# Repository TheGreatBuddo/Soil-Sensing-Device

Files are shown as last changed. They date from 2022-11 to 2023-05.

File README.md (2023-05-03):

# Soil-Sensing-Device Readme

Welcome to Twin Cities Engineering's project on soil health monitoring 
through gas-based measurement! Soil health plays a critical role in
agriculture and environmental sustainability. Measuring gases in soil pore 
spaces is an effective way to monitor soil health, providing valuable 
information about the soil's nutrient content and microorganism activity. 
However, commercially available gas-based soil health measurement devices 
are prohibitively expensive, limiting their accessibility to farmers and 
soil scientists. To address this issue, our engineering project team is 
developing a low-cost DIY soil gas sensing unit capable of 
measuring oxygen, carbon dioxide, and methane concentrations at 
four soil depths every hour. Our goal is to create a prototype 
that is affordable, portable, and easy to use, 
empowering more people to measure and monitor soil health.

Our project is centered around a device that attaches to four soil 
probes of varying lengths (0.25, 0.5, 0.75, and 1 meter) to extract 
soil gases. These probes are placed in a 1-meter squared area of soil, 
assuming that the soil gas concentrations will remain constant. 
The device has four ports for tubes that connect from the probes 
to the device, and each port connects to a solenoid valve inside the 
device. These valves can be opened and closed by a Mayfly microcontroller, 
allowing the device to be exposed to one probe at a time. 
A sensor chamber houses four sensors, including 
an Alphasense IRC-AT carbon dioxide sensor, Alphasense O2-A3 oxygen sensor,
and TGS2611-E00 methane sensor, along with a bme280 temperature, pressure,
and humidity sensor. The final component in the sensor chamber is a 
heating element, which is designed to prevent condensation from forming 
and potentially damaging the sensors. If the bme280 detects a dew point, 
the heating element is activated.

All work accomplished can be found in the Final Design Document and more
discussion about the project. A poster has been developed for this project
and is also uploaded in the repository. Lastly STL files for the sensor chamber
and the program to control the device are included.

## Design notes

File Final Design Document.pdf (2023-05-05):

Final Design Document

Twin Cities Engineering

Project Team Students: David Schaeppi, Samuel Day, Kevin Lee, Brendan Dykes, and Jeodaun Lee

Spring 2023 Semester

May 5th, 2023

## Contents

## Introduction

A revolution of farmers interested in smart regenerative agricultural practices has blossomed over recent years. Many farmers of these communities are actively seeking stem tools to help monitor soil health and provide feedback to farmers on the quality of their practice. One method to measure soil health is to measure the gases within the soil. Measuring certain gases in soil provides information about the nutrients and microorganism activity within the soil. Commercially available soil pore space gas instruments are costly, with the cheapest systems costing around $100,000. The high costs leave a demand for a low budget system capable of extracting, measuring, and reporting soil gas concentrations.

To address this issue, a team of engineering students from Twin Cities Engineering at the University of Minnesota, Mankato, is planning to develop a low-cost DIY soil sensing unit. The unit will be designed to extract soil gases from four different depths, providing farmers with valuable information about their soil health. The team plans to make all the information about the project available on GitHub, an open-source platform for software development, so that other farmers and researchers can benefit from their work. By developing a low-cost soil sensing unit, the team hopes to make it easier for farmers to adopt smart regenerative agricultural practices and improve the sustainability of their farming operations.

The DIY soil sensing unit will consist of a gas sampling chamber, a vacuum pump, and an electronic sensor for detecting the gases. The team plans to use off-the-shelf components wherever possible to keep the costs low. They are also exploring the use of 3D printing technology to produce some of the components. The device will be powered by a rechargeable battery, which will be recharged with solar power, making it easy to use in the field.

In addition to providing farmers with information about their soil health, the team hopes that their project will also help to raise awareness about the importance of soil health and the role of regenerative agricultural practices in promoting sustainable agriculture. By sharing their work on GitHub, they aim to inspire others to develop similar low-cost solutions and contribute to the growing community of farmers interested in regenerative agriculture.

Current State of the Art

There are a few longstanding methods of acquiring this data from under the soil, one being gas chromatography. This is done in a large lab space where samples of the trapped gas or soil sample are brough to the lab and examined in these large machines. The chromatography machine is, bulky, high-energy cost and high dollar cost. The next champion in this segment is the FTIR.

Fourier Transform Infrared (FTIR) spectroscopy is a powerful analytical technique that can be used to analyze the composition of specific gases in soil vapor. The technique involves measuring the absorption of infrared radiation by a sample and then using this information to determine the types and amounts of molecules present in the sample.

FTIR spectroscopy works by passing infrared radiation through a sample, such as soil vapor, and measuring the amount of radiation absorbed by the sample at specific wavelengths. Different molecules absorb radiation at different wavelengths, and the resulting spectra can be used to identify the types and amounts of molecules present in the sample.

When applied to soil vapor, FTIR spectroscopy can be used to identify and quantify the concentrations of various gases, such as carbon dioxide, methane, and nitrous oxide. These gases are important indicators of soil health and can provide valuable information about soil microbial activity, nutrient cycling, and greenhouse gas emissions. So the FTIR is a force. However, this is an industry machine that costs in 100k range and requires a great deal of power. More power than we could get out of a 2ftx2ft solar array

What is the Device:

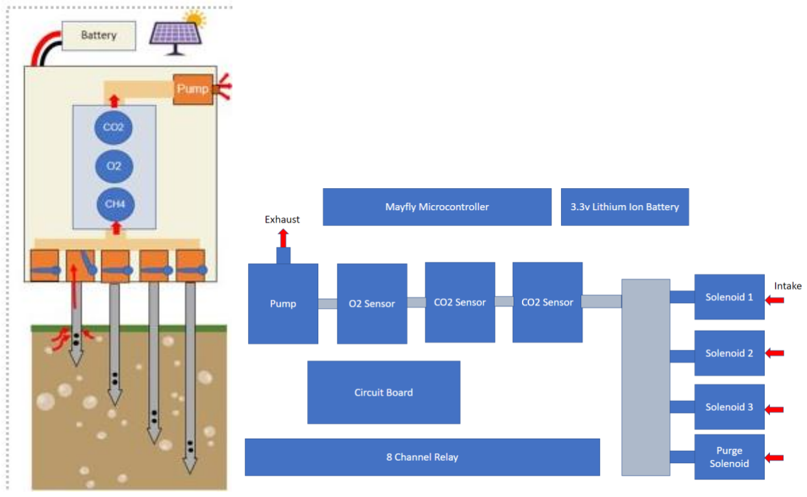
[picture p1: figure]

The images above are diagrams of the system we received from the previous team.

The Device a machine that will stay outside all growing season, it will use a solar panel to charge its batteries. It will be able to accurate a pump to draw gas from under the soil from 4 different depths, run that gas over our sensors and record the concertation of Co2, O2, and CH4. After the reading has been taken, the gas is removed from the chamber via that same pump and ejected through a port in the top of the machine. The data is then saved to an SD card as well as relevant information about Time, Date. Temperature, and Humidity.

## Project Tutorial

### Project Timeline

- Spring 2022
- Developed groundwork for entire soil sensing unit design
- Setup a pump, 8 channel relay and sensor hookup
- Fall 2022

- Created Sensor caps to connect sensors together
- Extracted readouts from sensors
- Programmed framework for device operation
- Data storage on SD card
- Eliminated solenoid noise triggering relay issue using snubbers
- Attempted to implement a methane sensor but fried it
- Spring 2023
- Created a sensor chamber included with temperature control
- Created a prototype bulk water removal system
- Fully implemented entire design into a box for total mobility
- Implemented a low-cost methane sensor
- Properly extract gas from probes
- Completed a GitHub Repository

### Device Design

Design Intent
The soil gas sensor device is designed to provide accurate and precise measurements of gas concentrations in soil. It consists of four soil probes of varying lengths (0.25, 0.5, 0.75, and 1 meter) that can be easily attached to the device. Each probe is equipped with holes to extract gas from the soil when a connected pump is activated.

To ensure accurate readings, the four probes are placed in a 1-meter squared area of soil, under the assumption that soil gas concentrations will not vary significantly within this area. The device itself has four ports to connect tubes from the probes to the device. Each port is connected to a solenoid valve inside the device, which can open and close based on the response from a Mayfly microcontroller.

To ensure precise measurements, the device allows for the exposure of one probe at a time while keeping all other valves closed. This process allows the device to accurately measure the gas concentration at each depth, providing valuable insights into the microbial activity and nutrient levels of the soil. By allowing for the measurement of gas concentrations at varying depths, farmers can make informed decisions about the timing and amount of fertilizer application, thus optimizing crop yields while reducing the use of potentially harmful fertilizers.

Behind the solenoids lies the sensor chamber. The sensor chamber houses an Alphasense IRC-AT carbon dioxide sensor, Alphasense O2-A3 oxygen sensor, a TGS2611-E00 methane sensor, a bme280 temperature, pressure, humidity sensor, and a heating element. The heating element is implemented due to our project team’s worry of condensation forming within the sensor chamber and damaging the sensors. The heating element is connected to an H-Bridge and begins heating if dew point is measured from the bme280.

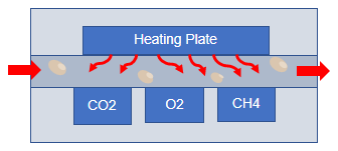
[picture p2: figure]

Figure 1

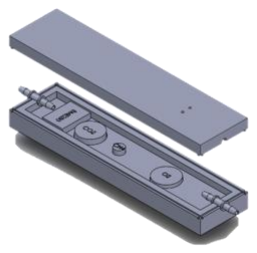
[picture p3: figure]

Figure 2

The Alphasense sensors were chosen due to professor suggestion in the reliability of the brand. Each Alphasense sensor is powered with 12V. To measure the sensors a load resistor of 230 ohms is used for both sensors. The voltage drop across the resistor is measured using an Analog Digital Converter (ADC) to read oxygen and carbon dioxide. The Alphasense IRC-AT has two signal wires. Sig+ connects to one end of the resistor while Sig- connects to the other end. The Alphasense O2-A3 however connects in series. 12 volts powers the O2-A3. The output current is an ADC measurable current of 4-20 mA. The load resistor is placed in series with the O2-A3 sensor for the ADC to measure the voltage drop.

The TGS2611-E00 was chosen due to its low cost and abundant literature claiming the sensor to be a capable low-cost sensor for methane detection. Our team lacks the ability to perform proper laboratory calibrations. Our team assumed we could use equations derived from literature [1] [2], to tune an algorithm to compute relatively accurate ppm readings from measured voltage drop across a load resistor. Our assumptions were wrong.

To compute the TGS2611-E00, ohms law is used to measure the resistance inside the methane sensor. The equation displayed in Equation 1Error! Reference source not found. is used to compute sensor resistance Rs
. For context the sensors circuitry is displayed in Figure 3. The Mayfly ADC measures voltage drop (Vout) across the load resistor Rl

Rs = RL (

Vc

Vout

− 1)
Equation 1

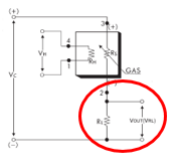
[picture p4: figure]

Figure 3: TGS2611-E00 Sensor Circuit

To convert the ADC’s measured voltage to methane parts per million our team attempted to use equations from Van den Bossche et al [1]. In their paper, Equation (11) converts sensor resistance to methane ppm using a value R0 and measured Rs displayed in Equation 1. R0 is the sensor’s resistance value at a reference point concentration of methane ppm. We recorded R0 in an ambient setting to be equal to 23,250 Ω. Our team recognized we had no way to control environmental factors such as temperature and relative humidity, but we could reference them using measurements from the BME280. When using the equation, we found the trend to compute confusing results. The equation also did not compute an expected trend.

The BME280 was chosen due to its ease of installation. The device has two total BME280s installed with addresses (0x76) and (0x77). (0x76) measures ambient temperature, pressure, and relative humidity within the container of the device. (0x77) measures temperature, pressure, and relative humidity within the sensor chamber. Both the BME280s are used to compare the difference between the ambient environment and inside the sensor chamber. If the temperature is excessively cold out, condensation could occur. Thus, the mayfly continually monitors the temperature and relative humidity inside the sensor chamber to acknowledge when to turn on the heating element.

Device’s Program Flowchart
Shown in Figure 4, the Mayfly microcontroller first reads if any of the bme280 sensors or the external ADC is properly connected. If any of the components are not connected, then the device will not operate. If all components are connected the code will reach Arduino’s loop function. Inside the loop function is a for loop intent on opening one solenoid valve out of four, pumping gas from the solenoid through the device, measuring data, heating the sensor chamber if necessary, and storing the data on a SD card located on the microcontroller itself.

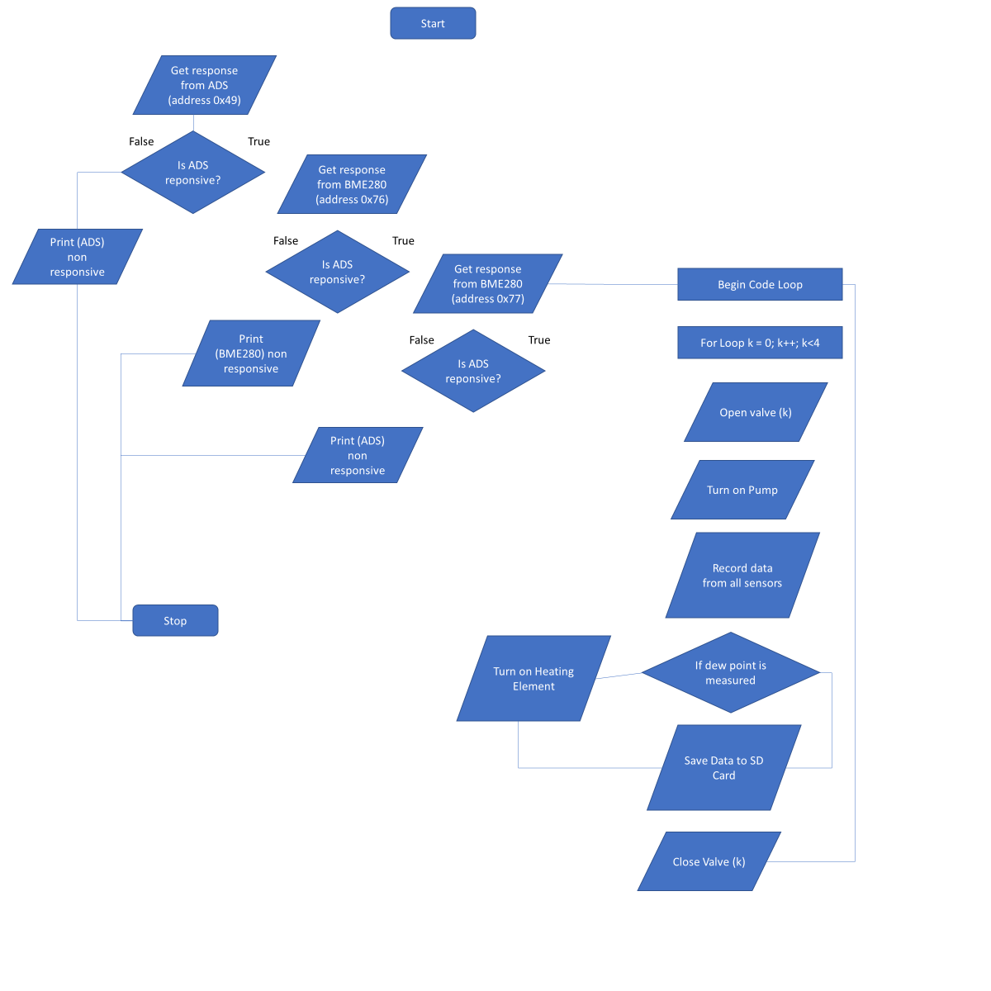
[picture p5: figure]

Figure 4: Program Flowchart

Device Electrical Schematic
The electrical schematic displayed in Figure 5 shows all electrical components wired in the device. At the center of it all, a Mayfly v1.1 microcontroller controls all the operations of the device. Both the Alphasense O2-A3 and the Alphasense IRC-AT voltage readouts are measured using an onboard ADC. An external ADC component, the ADS1115 measures the voltage level of the battery, and measured voltage drop across the load resistor of the TGS2611-E00 methane sensor. The solenoids are controlled with an 8 Channel Relay. Each solenoid is connected to the normally open position. Connected in parallel with each solenoid is a resistor and capacitor in series. These are snubbers intended to dampen AC noise generated when the solenoids are opened or closed. Our project team had a significant problem controlling the relays until the snubbers were installed. To control the pump and heating element, an L298N H-Bridge was used. The H-Bridge can limit voltage supply to the components used Pulse Width Modulation (PWM) from the Mayfly microcontroller.

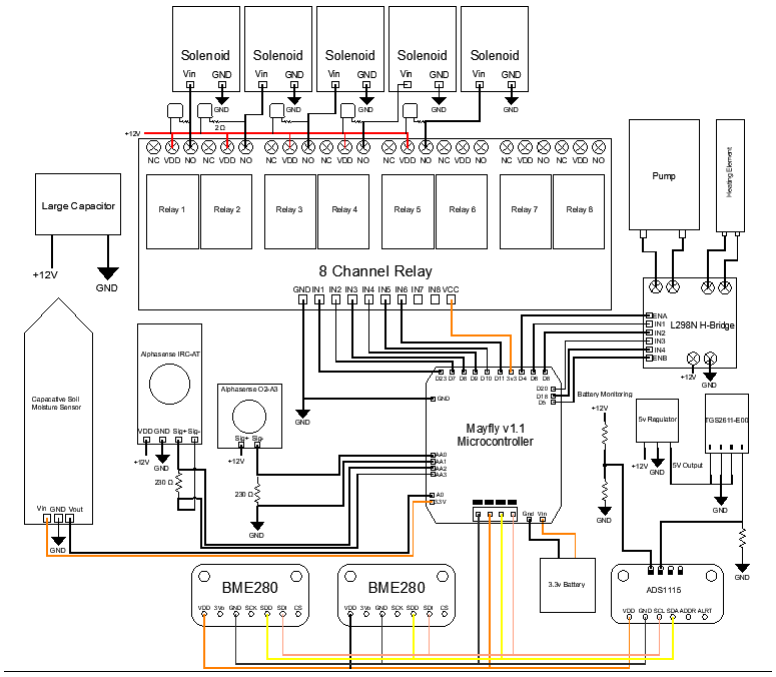
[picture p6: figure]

Figure 5: Electrical Schematic

The Mayfly Microcontroller was chosen due to its capabilities and the microcontrollers focus on being used to monitor environmental conditions in a DIY environment. The EnviroDIY community is behind this device. The Mayfly Microcontroller is based on Arduino and uses the Arduino IDE software for programming. The microcontroller is pivotal for our device because of its range of capabilities. The device uses I2C communication, Analog Digital Converters (ADC), pulse width modulation, and one of the most important points is the number of available pins. In total our device requires 23 individual pins to operate the device leaving the mayfly as a great option.

The solenoids are powered using 12V and controlled from the 8 Channel Relay. Placing the snubbers in parallel with the solenoids is important due to noise generated from the opening and closing of a relay. The noise generated would retrigger the relay even though there was no input. The relay would begin to spasm uncontrollably until the power was turned off. The snubbers absorb AC signal noise and prevent a commonly known issue of the relays going haywire. The solenoids themselves consume a lot of power, about 600 mA per solenoid. The solenoids have been used in all three semesters of this project because the solenoids met the need for testing and designing. All project teams were focused on function and not worried about power consumption.

The L298N H-Bridge is used to control the current supplied to both the pump and heating element using PWM from the Mayfly microcontroller. Both the pump and heating supply are wired to the same H-Bridge but are separately controlled to meet the necessary power consumption. In software the pump is operated at maximum speed to fill the sensor chamber as quickly as possible. For the heating element, about 2 volts was enough to heat the sensor chamber adequately but can be adjusted in the code to either increase or decrease heat output.

The ADS1115 is an Analog Digital Converter (ADC) used to measure the voltage at different points in a circuit. The Mayfly has four onboard ADC pins. Our team is using all four pins to measure the voltage drop across the load resistors of the carbon dioxide and oxygen sensor. Other components we need to measure are the TGS2611 – E00 methane sensor, and the battery voltage. Since our device is planned to eventually be powered by a solar panel, a battery monitoring system has been implemented. The ADS1115 measures from 0 – 5V, but we have it measuring up to 3.3V max due to a warning in the component’s documents. A 100,000-ohm resistor is placed in series with a 10,000-ohm resistor. Using the voltage divider equation and measuring the voltage drop across the 10,000-ohm resistor, the ADS1115 can safely measure voltage and the Mayfly can compute the total voltage supplied by the battery. Lastly the ADS1115 also measures the voltage drop of the TGS2611 - E00’s load resistor and an algorithm are used to convert and compute methane ppm.

The Capacitive soil moisture sensor is used to detect water inside the bulk water removal trap. The Mayfly measures voltage from an analog pin. Currently the program has not implemented any response to water level besides taking measurements. We suggest using measurements from the soil moisture sensor to operate designed water trap.

Water Trap
We chose to use the method of 3D printing to create a water removal unit for the soil project. Full well understanding two things that this method will be able to get a basic design or best shape but the difficult learning curve of the solid works software as this semester is the first time we have engaged with that software.

We started this off by disassembling a commercial water filter, the intent was to use a portion of this, and just print a coalescing tray that we could attach an actuated removal of the water. We took all the measurements of the parts we intended to replace.

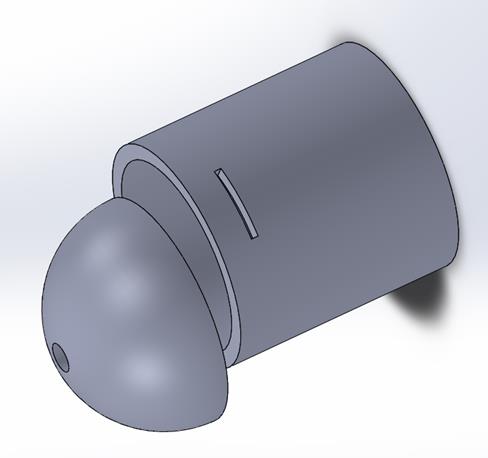
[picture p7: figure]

Figure 6: Screen capture from SOLIDWORKS of the first iteration

The plan at this point was to attach this to a commercial object that had a similarly shaped plastic container over a filter. Our design included a hole in the bottom of the dome, here we would attach the connection to the pump for the water removal. On the side of the Cylinder there is an area for the sensor to communicate the water height has reached its limit, stopping pumping gas in.

It was at this point that we realized the cost saving in just modeling and printing the whole thing ourselves. The whole unit could be assembled ourselves for ~$6.00 of PLA and $10.00 for off the shelf coalescing filter. The commercial filter was currently around $100.00.

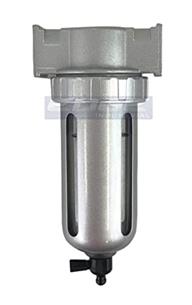
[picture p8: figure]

Figure 7: Example of the water trap (not the exact one) *image from Amazon.com MID FLOW PARTICULATE FILTER/WATER TRAP

printing the top portion came with new learning challenges. The first models are just the basic shapes and I couldn’t even figure out how to make one shape on another without making then separate parts.

The new design was going to incorporate two ports that connect to the hoses using the current iteration of the soil sensor prototype. One the intake port will be in the middle above the coalescing filter and the second will to the side of that this will be the exit port for the air now free of liquid water (at current temp).

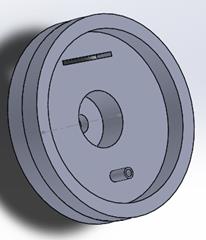
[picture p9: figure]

Figure 8: Screen captures from SOLIDWORKS; Figure is the underside the part.

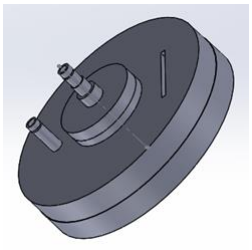
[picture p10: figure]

Figure 9: Screen captures from SOLIDWORKS; Figure is the top of the part.

At this point the plan was the inner walls around the center hole much thicker than the program would have had them as well as made the hole undersized for current purposes. The intent was to bore the proper threads in. A port was added to the top since now we could mount that water level sensor in the top.

The first prints suffered from my not building a design that print easy the large gaps of “ceilings” that this design had a high percentage of failure on the first layers trying to bridge those gaps. This more or less self-corrected after the first layer and the choice to make all the walls slightly thicker for water-tight consideration came in clutch.

Also on the second print the failure in the first layer tipped the interior outlet port over and failed to connect properly. After a few more iterations and the realization that the boring technique that was previously mention was not well understood and we then chose to try to print the threads to attach to the commercial filter

We took all the appropriate measurements of the threads: .771in Diameter of the connector with the threads .767in Diameter without threads (thread width was ~.004in), the connector was .28-inch-tall and displayed roughly 4.1 turns of the threads.

Using this data and the tools on SOLIDWORKS I was able to resize the whole to proper size and add the threading necessary to connect to the filter.

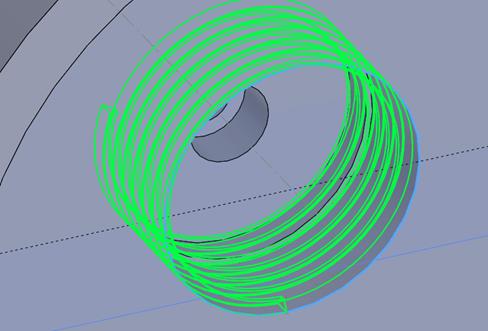
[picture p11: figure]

Figure 10: Screen captures from SOLIDWORKS the thread tool set to 16 thread per inch with .004 thick threads.

The Hosing connections were more just by trial and error (the inner diam of the tubing is not what you want if you want a good seal). During these last iterations I sized up the fittings on the top as well to create a nice seal and added a few ridges to them to help secure and prevent leakage.

Though this design technical works and worked for our demonstration, there is still need for iteration. A large flaw in the current design is that all the OD specs where create to allow attachment to another device we are no longer using. The greater the volume within the chamber the more water can be trapped before the machine will turn off (the more data it can gather) however the greater the volume of the trap the greater the volume of the whole system a system that. The added volume accounts for 80ml of air and needed to be flushed out with 3 times that volume. To guaranty with even a 95% accuracy that we can say “we know where the gas came from”.

So, in future iterations I will need to run simulations on the air flow, with the goal of reducing the volume in the chamber while still allowing for an acceptable amount of water to build before the machine has to turn off and purge the trap.

The 3D printing process has proven to be a great choice for prototyping and developing the water removal unit. This is because 3D printing enables fast production of parts, allowing for multiple iterations and testing of designs with minimal costs. As described in the methods section, the top and bottom parts of the unit required several iterations to optimize their design and ensure they meet the requirements for the project. The ability to make rapid design changes and improvements allowed us to achieve a functional unit that performs well in collecting water from gas drawn from under the soil.

This process was done over about a weeks’ time, if I had tried to get this injection molded or vacuum formed, not only would it have costed hundreds if not thousands for the proper mold to be fashioned to create my part. It would have taken weeks to get those molds made. Each iteration the same costs and time would apply…perhaps for a larger print run of the final iteration that way would could insure that the final iteration would be air and water-tight. Until then 3d printing is the best option.

Calibration protocol
We designed a method for cheap calibrations last semester and even though the hand make calibration gas was within +/- 4% the amount of gas created was 100ml each time. For our calibrations this semester we intended to use a more established method.

The process of making calibration gas using flow meters typically involves the following steps:

1. Select the appropriate gas mixture: The first step in making calibration gas is to select the appropriate gas mixture that matches the gas you want to calibrate. This is usually done by consulting the specifications or requirements of the instrument or sensor being calibrated.
2. Assemble the equipment: Once the gas mixture has been selected, the next step is to assemble the equipment needed for the calibration process. This typically includes a gas cylinder or source, a pressure regulator, flow meters, tubing, and a gas mixing chamber.
3. Set the flow rates: The next step is to set the flow rates of the individual gases using the flow meters. This is typically done by adjusting the flow control valves on each flow meter to the desired flow rate. The flow rates are typically specified in the instrument or sensor calibration documentation.
4. Mix the gases: Once the flow rates have been set, the individual gases are then mixed in the gas mixing chamber. The mixing chamber is typically designed to ensure that the gases are thoroughly mixed to achieve the desired gas mixture.
5. Verify the gas mixture: Once the gases have been mixed, it is important to verify the gas mixture to ensure that it matches the specifications of the instrument or sensor being calibrated. This is typically done using a gas analyzer or other measurement equipment.

It is important to note that the specific process for making calibration gas using flow meters can vary depending on the specific instrument or sensor being calibrated and the gas mixture being used. It is also important to follow proper safety procedures when working with gas cylinders and other equipment to prevent accidents or injuries.

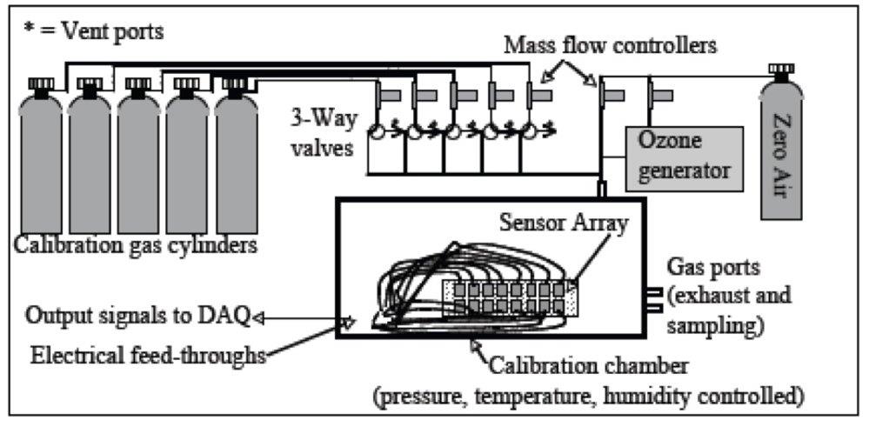
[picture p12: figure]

Figure 11: Calibration Setup Diagram

The Mass flow controllers are between $1500-$2000 a piece and the current layout has at least 4 of them. The good new TCE has many of these flow controllers! However, we did have any of the wires, instructions, or “Controllers” that allow humans to interface with the flow controllers.

We did a good deal of research, found all the instructions, and concluded that this set up would not only cost 2 weeks' time to assemble but that the setup was so cumbersome that few people that would be interested in this DIY project would have the aptitude or resources to invest with this set up.

Because of these set back and realizations we rescoped and went back to the 3-point tests for calibration using the method from last semester using this we got our methane senor calibrated and created an algorithm for turning the output from the sensor to a PPM scale.

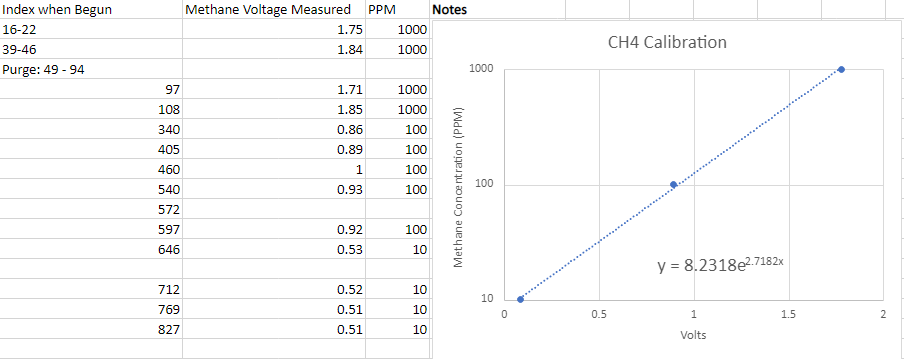
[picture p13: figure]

Last semester’s (Fall 2022) calibration method is attached as an appendix(i)

Motivations
The health of soil plays a crucial role in the success of agricultural production, and farmers can improve crop yields and reduce the use of fertilizers by understanding the level of microbial activity in the soil. Soil gas sensors are useful in this regard as they can detect methane or carbon dioxide which are byproducts of microbial decomposition, an essential process in the soil nutrient cycle. The concentration of these gases provides information about the level of microbial activity and the rate of decomposition, which helps farmers make informed decisions about the timing and amount of fertilizer application.

The use of soil gas sensors enables farmers to reduce their dependence on expensive and potentially harmful fertilizers by applying them only, when necessary, thus reducing the environmental impact of agriculture. Furthermore, optimizing fertilizer use promotes soil health and leads to increased crop yields, ultimately contributing to improved food security.

## Results

Our team attempted to perform experimentation on our soil sensing unit while it was operating. We found during calibration; we could not achieve accurate repeatable values with the installation of the new sensor chamber. Our team also desired to test gas extraction from soil, but since we failed to calibrate properly, we did not investigate the functionality of gas extraction from soil.

## Discussion

### Challenges and Solutions

Mayfly Microcontroller Driver Issue
Our team faced a problem with the Mayfly Microcontroller near the end of the semester. In some way shape and form the on-board ADC stopped operating as expected. Only a week later the USB connector on the mayfly suddenly felt loose and would not snap in as normal. The problems prevented us from uploading new code or reading measurements from the current Mayfly installed in our system. Luckily, we have backup Mayfly Microcontrollers, but we were unable to get use out of them. We found while attempting to upload a program on the different Mayflies, an error “stk500_recv(): programmer is not responding” would repletely display in the output terminal of the Arduino IDE if verbose was turned on in IDE settings. Tracing the error on forums, our team found the issue was likely related to FTDI drivers needing to be installed. However, in our attempt to install the drivers the issue persisted. Our team can only assume we installed the drivers incorrectly. Since our semester is ending, the new semester will have to solve this issue to get the soil sensing device operational again.

Calibration problems
Calibration of methane sensors involves adjusting the sensor's output to match the expected readings for a given concentration of methane gas. This process typically involves the use of specialized equipment, such as gas mixers and calibration standards, which can be costly. In this case, the team decided not to proceed with the calibration because of the cost involved. This decision may have been based on a variety of factors, such as budget constraints, competing priorities, or a belief that the sensor would still perform inadequately. It's worth noting that the decision not to proceed with the calibration of the methane sensor can have consequences beyond just the cost involved. Failing to calibrate the sensor can lead to inaccurate readings.

Use of sintered steel probes
Sintered steel is a type of porous metal material that is commonly used in filtration applications where it is necessary to block particulate matter while allowing gases or fluids to pass through. In the context of soil gas sampling, sintered steel can be used to create a course filter that prevents soil particles and other debris from entering the metal probe while still allowing gas from beneath the soil to pass through.

The sintered steel filter is typically located at the tip of the metal probe and acts as a barrier that prevents soil particles and other debris from entering the probe. The filter is composed of a network of interconnected pores that are small enough to block particles but large enough to allow gas to pass through. This ensures that only clean gas from the soil is sampled, without any contamination from soil particles or other debris.

The use of sintered steel filters in soil gas sampling is an effective way to ensure that samples are representative of the gas present in the soil without any interference from particulate matter. This is important because particulate matter can alter the composition of soil gas samples, leading to inaccurate readings and incorrect conclusions about soil health or other factors of interest.

When sintered steel filters are welded to a solid steel tube, there is a risk of compromising the overall strength and durability of the probe. Welding can introduce weak points in the probe that may break or deform under pressure or resistance, potentially causing damage to the probe or affecting the accuracy of soil gas measurements.

In some cases, sintered steel filters have been found to break at the weld when they come into contact with great resistance. This can be a serious issue in field applications where probes may encounter resistance due to soil conditions or other factors.

To mitigate the risk of structural failure in soil gas sampling probes, it is important to carefully design and construct probes with the appropriate materials and techniques. This may involve using stronger materials or alternative welding methods to ensure the overall strength and durability of the probe.

Overall, while sintered steel filters offer many benefits for soil gas sampling, it is important to consider the potential downsides of welding them to a solid steel tube. Careful attention should be paid to the overall structural integrity of the probe to ensure accurate and reliable soil gas measurements in the field.

Flowrate loss with current solenoids
During experimentation with our device, we tested our tubing for extracting gas from the solenoids to the sensor chamber and then to the pump. We found a large pressure drop from the solenoids which we believe diminished the device’s gas extraction rate. This semester we do not have the time to replace the solenoids with more efficient ones, so we are left with extracting at a very slow flow rate even with maximum pump rate.

Methane sensor oxygen dependence
One key issue with the current Figaro TS2611-E00 methane sensor is the strong oxygen cross sensitivity. We recognized our sensor will operate in an anoxic (low oxygen) environment. We also expected the TS2611-E00 to have a cross sensitivity to varying oxygen concentrations. We tested the issue using argon to purge the oxygen from the sensor chamber. We did not expect the oxygen cross sensitivity to be many times larger than the humidity and temperature cross sensitivities. This strong oxygen cross sensitivity means the sensor will be least accurate when the methane concentration is potentially high enough for the sensor to measure. This severely limits any possibility of collecting any useful data with the Figaro TS2611-E00 methane sensor in a soil gas sampling application. Two possible solutions are discussed in Future Recommendations.

Device Wire Management
The circuitry of the device was soldered onto a smaller soldering board. When installed our team had a lot of trouble getting access to components inside the box with the circuit’s wires in the way. A new larger soldering board was added, replacing the old one. This soldering board has terminals to allow users to change wires around easily and without hassle. Still the board is large and wires inside the box still do not have much room.

### Future Recommendations

Methane Sensor
In the Challenges and Solutions we discussed the TGS2611-E00’s strong oxygen dependence and how it does not fit our purpose due to the accuracy severely worsening in the target anoxic environments. Our team found a possible replacement, the Cubic brand Gasboard2502 TDLAS methane sensor. The price is $2,300 per sensor with an accuracy of +/-5ppm and a repeatability of +/-1.6ppm. This may not be accurate enough for useful methane measurements in dry soil with methane in the 2-10ppm range, but it will almost certainly have adequate accuracy for anoxic conditions with methane in the 25-100ppm range. The Gasboard2502 sensor will double the device component cost.

No Methane Sensor
The other option is to not include a methane sensor. This allows an attractive alternative design, the “sensors in probe” design. This design almost certainly requires not using a methane sensor. The sensors in probe design eliminates many components, including the air pump, air solenoid valves, air manifold, water valve, water separator, sensor chamber, heater, and plumbing. This leads to advantages in reduced power use, lower design complexity, and fewer points of failure. The main challenge with the sensor in probe design is keeping the liquid water out of the sensors. This is the most likely point of failure. This design may use hydrophobic membrane filters, plugs made from sintered hydrophobic material, or some other method to keep water out (grey sections of exterior shell).

“Sensors in probe” description
The CO2, O2, and temperature humidity combination sensors are removed from their circuit boards and inserted into the soil probe. The sensors are connected remotely to their circuit boards with ribbon cable. Liquid water is prevented from entering with a hydrophobic filter or similar. The hydrophobic filter allows soil gases to diffuse through it. The probe has duplicates of each sensor in separate chambers at each soil depth. The sensors may be assembled onto a frame that in slid into the tube as one piece. A seal of caulk or an O-ring between each set of sensors would prevent soil gas mixing vertically in the tube.

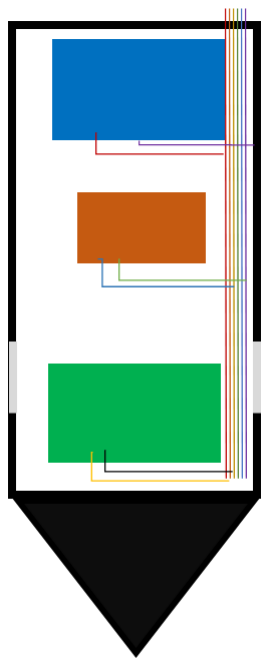
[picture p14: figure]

Sensor in probe design detailed view.

Sensor in probe complete probe layout.

Applying regression to create a calibrated algorithm
Based on the actions from literature, using statistical analysis tools such as regression improves algorithm calibration. We recommend using two-point calibration and linear regression to improve calibration results. Setting up an experiment to calibrate the methane sensor alongside a temperature, humidity sensor could allow better calibration even in environments with changing temperature and humidity. Our recommendations come from work done by Bastviken et al [2].

Design Issues
Currently the sensors installed in the device are connected to the 12V supply or 5V supply without any on or off switch. In the future wire the sensors to connect to relays. Wiring the sensors to a relay could reduce power consumption for a long time simply by turning the sensors on or off when needed. Keeping in mind the sensors do need time to warm up. The sensors warm up in about 30 seconds, but more accurate measurements are possible at 30 minutes. Weighing the cost benefit is necessary if making this change.

Currently, the mayfly microcontroller in the device is supplied by a separate 3.3v battery. In the future, connecting the mayfly to the main power supply would prevent the risk of the mayfly running out of power. Eliminating the 3.3v battery would also eliminate the need for a person to continually replace the battery when servicing the unit. Lastly, eliminating the battery could increase space inside the unit. If necessary, incorporating the 3.3v lithium-ion battery as a backup could be useful. The current design recognizes the method for analyzing supply battery voltage, but no work has been done to implement a stop mechanism for when battery voltage reaches a certain low.

The current installed Solenoids are a problem for the device for three reasons. 1) the current solenoids are bulky and difficult to connect to. 2) The solenoids consume an abundance of power, way more than necessary. 3) The solenoids cause problems with the flow rate of the device. With different solenoids the device may be able to extract gases better, consume less power, and be easier to install. Overall, the solenoids are to expensive in terms of space, and power. Other smaller solenoids exist with much less power consumption making the current solenoids obsolete.

The current sensor chamber and pipe system for delivering gases extracted from probes has problems. The sensor chamber leaks due to being printed from PLA, and its inside volume is much larger than necessary. To resolve these issues, we recommend creating a sensor chamber with a leak-proof material and optimizing its inside volume to maximize gas contact with the sensors. Reducing the sensor
chamber volume will also decrease pumping time and lead to long-term energy savings.

Our team implemented a battery level monitoring system using a voltage divider and a single pin from the ADS1115 ADC. However, we created a new circuit board for the system including terminal screws instead of hardwired soldered connections. The new circuit board lacks the voltage divider created on the previous circuit. Reimplementing the battery monitoring system would be useful. The voltage divider can be seen in Figure 5: Electrical Schematic. When a battery operates, its terminal voltage decreases when losing power. Performing a power drain test with the battery monitoring system will show at what voltage the battery is at low power. The device can then be programmed to perform actions based on low battery voltage.

In the Fall 2022 semester, time readouts were implemented into the Arduino program. In Spring 2023, our team did not focus on time. Slowly the time measurements became inaccurate and unusable as the internal clock drifts. Perhaps time could be adjusted using Fall 2022 program found in the GitHub repository. Our team recommends correcting the time readouts for useful context when datalogging. Instructions should be made for the client to periodically correct the internal clock time.

During this Spring 2023 we found calibration difficult and expensive. To perform proper laboratory calibration requires a lot of resources. Our team found our calibration procedure using a 10 ml syringe to be cost-effective and useful. Despite the absence of advanced laboratory equipment or specialized knowledge, our method has demonstrated efficacy in conserving resources and time. Nevertheless, the project is an open-source DIY resource for people. The syringe calibration method could be useful to the open-source community, but perhaps finding a commercial resource could provide value to next semester’s team and the open-source community.

Gantt Chart for Fall 2023
Our team created a Gantt Chart we expected would be reasonable for next semester’s team. The Gantt Chart includes objectives and tasks already scoped for a team to reasonably finish the objectives by the end of the Fall 2023 semester. However, this is a template and created a lot of value for our team in the Spring 2023 semester. Using a Gantt Chart provides accountability for your team to accomplish tasks in a timely manner. Our team recommends using our Gantt Chart and altering it to accommodate the problems faced during the semester.

## Conclusions

In conclusion, The Spring 2023 soil sensor team focused on developing a low-cost, DIY soil sensing unit that can extract, measure, and report soil gas concentrations from four different depths. This project addresses the high cost of commercially available soil pore space gas instruments, which can hinder farmers' ability to monitor their soil health. The project has been ongoing with Spring 2023 being the third semester of the project. The Spring 2023 team created a prototype sensor chamber and a prototype water trap. Our team was able to implement the sensor chamber into the design and implement program logic to operate the heating element inside the chamber. The water trap design was 3D printed, but unfinished and untested. Our team installed a TGS2611-E00 methane sensor into the soil sensing unit but found and later validated the sensor reacted improperly to anoxic environments. A new circuit board was implemented with screw terminals to improve wire management and improve a user’s ability to change around components. The conversion to a new circuit board eliminated the battery monitoring feature installed on the previous circuit. Our team explored what resources would be necessary for proper calibration of our device and found the resources to be very expensive. Our team stuck with a syringe method because of the low cost and easy applicability. Our team created a Gantt Chart for the Fall 2023 semester for the next team to use as an outline. The Gantt Chart supports a lot of our recommendations for the next team to perform in the future.

## Program and supporting Resources

The program and supporting resources such as STL files, a condensed Final Design Document, Technical Poster, and more information about the project can be found on our GitHub repository with the link provided. https://github.com/TheGreatBuddo/Soil-Sensing-Device.git

## Appendix i - Calibration

This Calibration Protocol will be run using the existing concepts of volumetric measurements and serial dilutions to correctly create our own calibration gas. This step is necessary to confirm the data sheet information and set up our equations to convert the output to proper percentages and ppm. We will do this by passing 100ml of our calibration gas over the sensors. We will first cover the Items necessary for calibration, The warmup time of the sensors, then cover O2 Sensor calibration then the CO2 Sensor, and lastly the CH4 Sensor.

Note: This Method was tested against 2 off the shelf handheld CO2 Stafty sensors, Accuracy of method was withing ±20ppm

The Required Objects

- Blackburn, 16g Threaded CO2 refills
- Blackburn Inflator
- One Tank of Argon, Compressed
- Methane Calibration Gas (1000 ppm, Nitrogen Balance, 17 Liter
- 100ml luer lock plastic syringe
- 10ml luer lock plastic syringe
- 2 male to female luer lock tips .167 in OD (M2F-ll)
- 3-inch section of .25 OD soft plastic tubing
- 0.50-inch section of .25 OD soft plastic tubing
- ~15 Balloons (Container for our gas CO2 and Argon)
- Soil Vapor Device

The first test is the Warmup time of the sensors. In this Test we will set up the system and turn on the pump and the sensors in series, as well as have the mayfly logging the data. Allow the system to run uninterrupted for 1 hour. While the systems are running, all the ports are drawing from the “same” ambient air not placed in the ground. The intent is to look at the data afterwards and find the point at which the values stabilize. Then compare those results to the values on the data sheet.

The first calibration test was performed to check the 0 values on the sensors. This was achieved by venting some gas from the compressed Argon into a balloon for storage. Then the balloon is attached to the top of the 100ml Syringe by pinching 1 inch from the inlet and stretching the remaining balloon over the syringe. Draw 100ml out of the balloon, because of the pressure in the balloon this will affect the size of the balloon less than one would think. Once you have the 100ml pure Argon calibration gas, we will attach the M2F-ll tip to the 3-inch tube and then affix the other end of the tube to the sensors. Attach the syringe to M2F-ll (some of the Argon will expel as the pressure equalizes between the syringe and the ambient air pressure- this is expected and will not affect current process). Turn the power on the pump off. Mark the time for reference and push the 100 ml of gas over the sensors for 10 seconds. Log the data and track the lowest values that are output from the sensors. After 0 value test, reattach the pump to clear the line back to ambient values. Repeat this calibration step 2 more times and use the lowest values. This data will be used as the zero value to detect change. ie: if 1.1v is the 0 value then and the next tested value is 1.3v that is a change of .2v) this will be used later for ppm calculations.

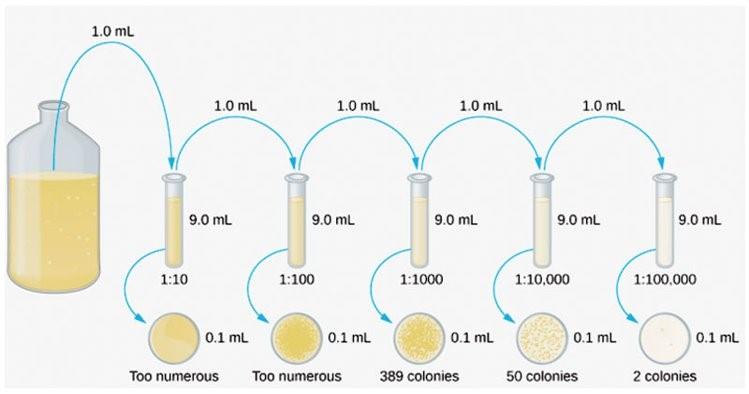
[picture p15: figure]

The second calibration test will be testing the O2 sensor with 5%,10%,15% concentration of O2. Each of these calibration values will be tested 3 times for repeatability and accuracy. To create our calibration gas for O2 we will need to assume that ambient air is ~20.9 O2. Then we can set up the equation y=20.9x where y is the goal for the % of o2 being tested.

Ie: @5%

5=20.9x ⇒ 5/20.9=x ⇒ x= 0.239

So, with this we can convert that into 23.9% of the 100 ml of gas in our syringe.

First Draw 76.1ml of argon from the balloon into your 100ml syringe. Remove the balloon and attach the M2F-ll. At this point the argon will decompress to ambient pressure and you will begin to draw in the remaining 23.9ml of air. This is now a 5% O2 concentration of calibration gas. Turn the pump off and attach the 100ml syringe to the sensors in series and mark the time. Administer the 100ml over a 10 second period. Log the data and then attach the pump again to purge the system with ambient air until normal values return (~20-30 seconds).

The same math and method can be applied to each of the other values:

@10%

10/20.9=x ⇒ x= 0 .478

Thus, start with 52.1 ml Argon and then draw in 47.8 ml of air to creating 10%

@15%

15/20.9=x ⇒ x= 0.718

Here, start with 28.2 ml of Argon and then draw in 71.8 ml of air to create 15%

Note: First iteration of the calibration test used CO2 as the balance gas for the O2 sensor however O2 sensor has a CO2 sensitivity, if the CO2 is above 5% (50,000 ppm) these levels are unexpected in the field use of this device however when exposed to even the lower value of 28% CO2 the sensor itself would output roughly 37% expected amperage.

The Next sensor to calibrate will be CO2. We will use a similar method to the O2 sensor however we will need to employ a process called serial dilution to achieve the smaller required values of 1000 ppm, 2000 ppm, 3000 ppm, 4000 ppm and 5000 ppm. Start out with one balloon of argon gas, and then create a second balloon with CO2 gas. To do this screw one of the 16g threaded CO2 cartridges into the Blackburn Inflator, pull the balloon over the dispenser nozzle and over the back of the dispenser. Pinch around the neck of the inlet again and pull the nozzle back slowly to release some of the CO2 from the cartridge. Once both balloons are ready, then prepare the 0.5-inch soft plastic tube with both M2F-ll tips inserted on either side of the tube (ideally touching inside the tube to reduce contamination) hereafter referred to as “docking tube”. After that, use the 100 ml syringe to draw 95 ml of argon. Then use the 10 ml syringe to draw 5 ml of CO2 out of the other balloon, attach both syringes to the connecting docking tube to draw the 5 ml CO2 into the 100 ml syringe. At this point we have a 5% concentration or 50,000 ppm, allowing time for diffusion (~5-10 second). Now implementing the serial dilution process, if we want to reduce the current concentration by a factor of 10, we can transfer 10 ml of the 5% concentration back to the 10 ml syringe. Then expel the remaining gas in the 100 ml syringe. Next, draw another 90 ml of pure argon from the balloon and reattach it to the docking tube. Return the 10 ml 5% concentration to the 100 ml syringe and now a 0.5% concentration of CO2 or 5000 ppm. Lastly remove the 100 ml syringe and one of the M2F-ll tips to attach to the sensors in series, turn off the pump and mark the time. Administer the gas over the standard 10 second window. Log data, turn the pump back on to clear the line and return to ambient values. Then repeat 2 more times for 5000 ppm. Note: the 5000 ppm should be the max the sensor will detect thus should receive max output.

This same method will be used to get other values

@4000 ppm

Start with the 100 ml syringe with 96 ml of argon and the 10 ml syringe with 4 ml of CO2 attach both to the docking tube draw 4 into 96 and allow time for diffusion. Transfer 10 ml back to the 10 ml syringe @4% concentration then dilute into another 90 ml argon to achieve 4000 ppm

@3000 ppm

Start with the 100 ml syringe with 97 ml of argon and the 10 ml syringe with 3 ml of CO2 attach both to the docking tube draw 3 into 97 and allow time for diffusion. Transfer 10 ml back to the 10 ml syringe @3% concentration then dilute into another 90 ml argon to achieve 3000 ppm

@2000 ppm

Start with the 100 ml syringe with 98 ml of argon and the 10 ml syringe with 2 ml of CO2 attach both to the docking tube draw 2 into 98 and allow time for diffusion. Transfer 10 ml back to the 10 ml syringe @2% concentration then dilute into another 90 ml argon to achieve 2000 ppm

@1000 ppm

Start with the 100 ml syringe with 99 ml of argon and the 10 ml syringe with 1 ml of CO2 attach both to the docking tube draw 1 into 99 and allow time for diffusion. Transfer 10 ml back to the 10 ml syringe @1% concentration then dilute into another 90 ml argon to achieve 1000 ppm

Mark the time of each calibration run and its value being tested for later reference against the logged data.

Lastly The CH4 Sensor calibration will be very similar to the CO2 calibrations we will be using the argon balloon but now we need to create the CH4 gas balloon by attaching the balloon to the value and expelling some gas into the balloon. The CH4 gas is 1000 ppm to start with and the goals are to archive values for 10 ppm, 50 ppm, 100 ppm, & 150 ppm. Using a similar equation to the first calibration y=1000x, where y is our desired ending concentration

@100 ppm

100/1000=x ⇒ x=0.10

Start by Drawing 90 ml of Argon into the 100 ml syringe and then drawing 10 ml CH4 into the 10 ml syringe attach both to the docking tube and transfer the 10 to the 90 to create a 100 ppm concentration.

@75 ppm

75/1000=x ⇒ x= 0.075

Start by Drawing 95 ml of Argon into the 100 ml syringe and then drawing 7.5 ml CH4 into the 10 ml syringe attach both to the docking tube and transfer the 7.5 to the 92.5 to create a 75- ppm concentration.

@50 ppm

50/1000=x ⇒ x= 0.05

Start by Drawing 95 ml of Argon into the 100 ml syringe and then drawing 5 ml CH4 into the 10 ml syringe attach both to the docking tube and transfer the 5 to the 95 to create a 50-ppm concentration

@25 ppm

25/1000=x ⇒ x= 0.025

Start by Drawing 97.5 ml of Argon into the 100 ml syringe and then drawing 2.5 ml CH4 into
the | 10 ml syringe attach both to the docking tube and transfer the 2.5 to the 97.5 to create a
25 | ppm concentration

Note: the CH4 calibration gas is at 1000 ppm or 20% of LEL. This CH4 concentration is not explosive in a normal atmosphere with 20.9% ambient O2 and is within NIOSH (National Institute for Occupational Safety and Health) safety standards for human exposure for up to 8 hours with sufficient ventilation.

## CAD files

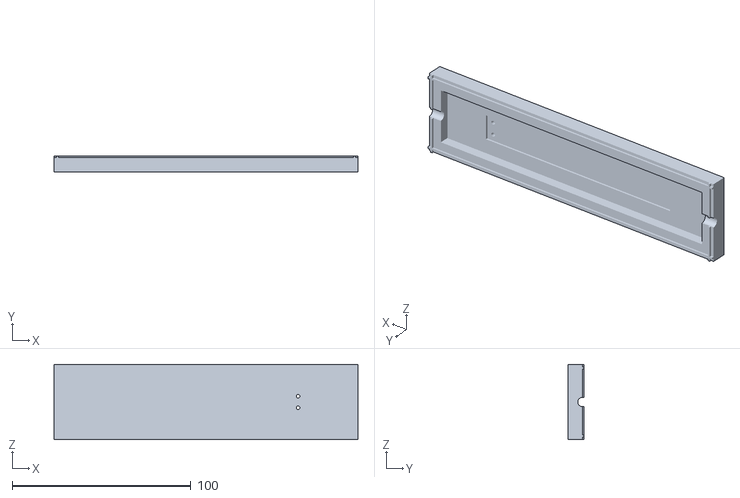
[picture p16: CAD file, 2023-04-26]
STL Files/Chamber Top Plate.STL
170.0 x 9.00 x 42.0

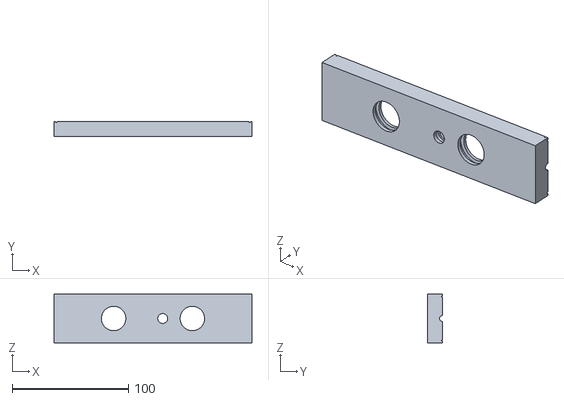
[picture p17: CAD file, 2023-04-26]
STL Files/Chamber Bottom Plate.STL
170.0 x 13.0 x 42.0

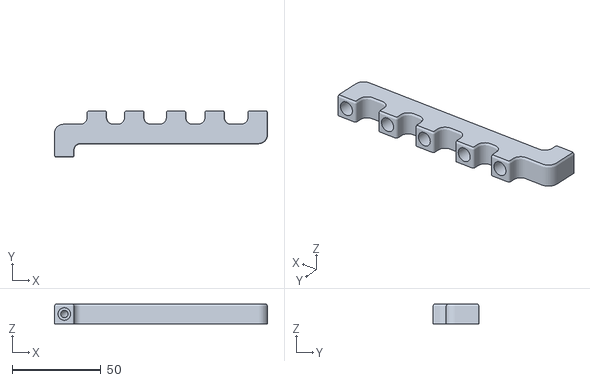
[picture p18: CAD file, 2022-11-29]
STL Files/Manifold.STL
119.8 x 26.0 x 11.0

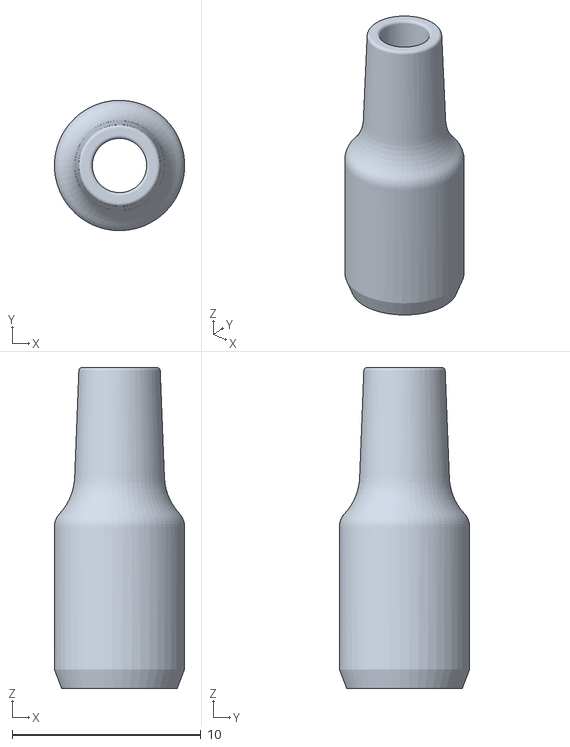
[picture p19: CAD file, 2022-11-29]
STL Files/Manifold_End_Plug.STL
6.90 x 6.90 x 17.0

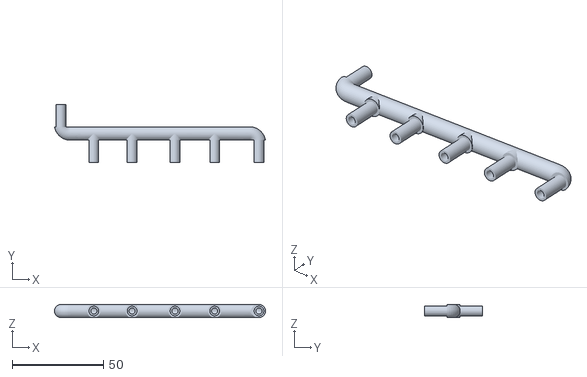
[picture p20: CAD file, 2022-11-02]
STL Files/Soil Sensor Project Air Manifold.STL
115.7 x 32.0 x 7.35

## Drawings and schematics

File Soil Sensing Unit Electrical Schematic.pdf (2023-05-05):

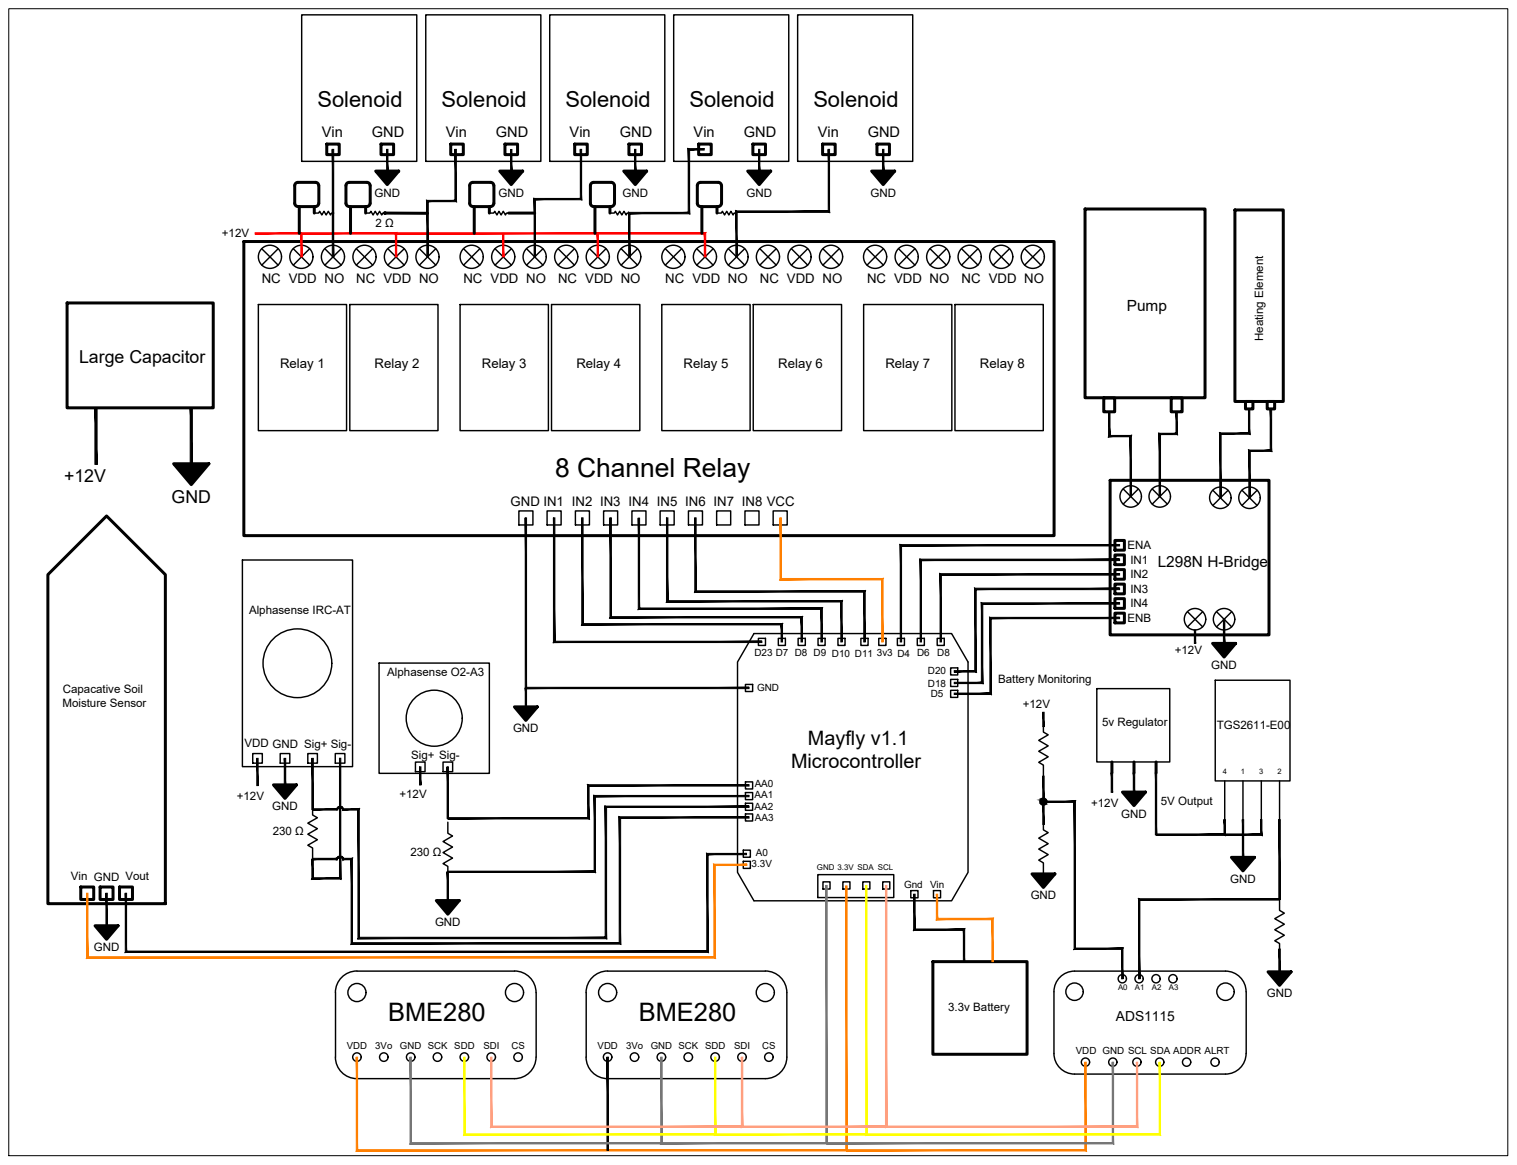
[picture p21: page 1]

Heating Element +12V GND ENA IN1 IN2 IN3 IN4 ENB L298N H-Bridge +12V Capacative Soil Moisture Sensor Vin GND Vout GND 230 Ω 230 Ω +12V GND GND GND GND GND 3.3v Battery Large Capacitor +12V GND 2 Ω

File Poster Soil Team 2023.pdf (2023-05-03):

## Low-Cost Device for Measuring Soil Health

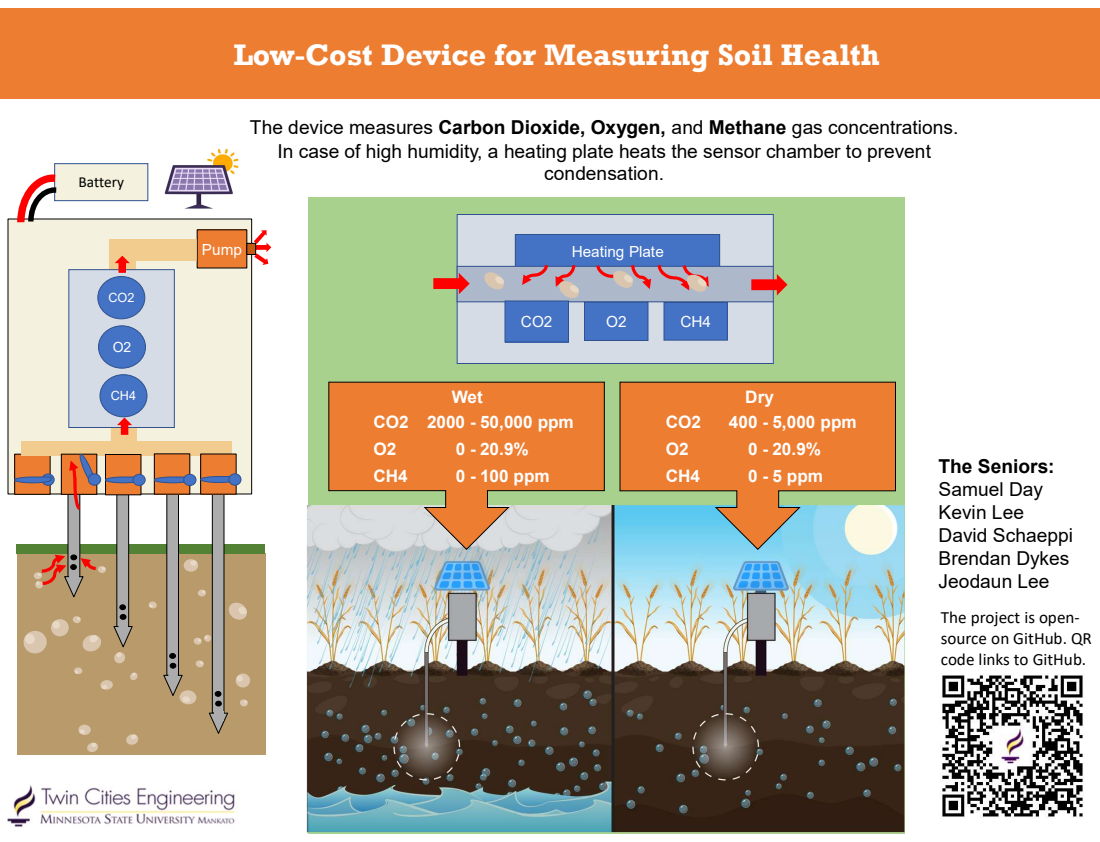
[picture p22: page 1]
condensation.; Battery; Pump; Heating Plate; Dry; 400 - 5,000 ppm; 0 - 5 ppm; Wet CO2 2000 - 50,000 ppm; 0 - 100 ppm

The device measures Carbon Dioxide, Oxygen, and Methane gas concentrations.
In case of high humidity, a heating plate heats the sensor chamber to prevent

The Seniors:
Samuel Day
Kevin Lee
David Schaeppi
Brendan Dykes
Jeodaun Lee
The project is open-
source on GitHub. QR
code links to GitHub.

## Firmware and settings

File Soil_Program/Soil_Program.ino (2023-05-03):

//Include libraries for the Arduino and I2C
#include <SPI.h>
#include <Wire.h>
#include <Arduino.h>
#include <math.h>

//Includes the Library for the Analog Digital Converters
#include <Adafruit_ADS1X15.h>

//Includes the libraries for the BME280 sensor
#include <Adafruit_Sensor.h>
#include <Adafruit_BME280.h>

//Includes the library for the SD card
#include <SD.h>

//Includes the Library for the Real Time Clock
#include <DS3231.h>

//Defines Sea Level Pressure for BME280
#define SEALEVELPRESSURE_HPA (1013.25)

//Adds Definitions to the SD pin and File info for SD card
#define SD_SS_PIN 12
#define FILE_NAME "Test1.txt"
#define LOGGERNAME "Mayfly Soil Vapor Sensor"
#define DATA_HEADER "Date,Time,Solenoid Number,Heater State,Water Level Measurement,O2(%),O2 Volt,CO2(PPM),CO2 Volt,CH4(PPM),CH4 Volt,Ambient Temperature (C),Ambient Humidity (%), Ambient Pressure (hPa), Temperature (C), Humidity (%), Pressure (hPa)"

//Creates Clock Variable for RTC
DS3231 Clock;

//Sets RTC Parameters
bool h24;
bool PM;
bool Century;
String sensor;
const int chipSelect = 10;
int second, minute, hour, month, DayMonth, year;

//Creates variables for different ADCs
Adafruit_ADS1115 ads1;
Adafruit_ADS1115 ads2;

//Creates variables for the BME280s
Adafruit_BME280 bme1;
Adafruit_BME280 bme2;

//Setting variables for the ADC results
int16_t results1;
int16_t results2;
int16_t results3;
int16_t results4;
float multiplier = 0.125F;
float O2_Volt;
float CO2_Volt;
float Battery_Lvl;
float Methane_Volt;
float O2_Percentage;
float CO2_PPM;
float Methane_PPM;
float accuracy_modifer;
float O2_Actual_Percentage;

//Creates variables for BME280 results

float atemp;
float apressure;
float ahumidity;
float temp;
float pressure;
float humidity;



int solenoid;
int k;
// Setting Valve pin
int flushPin = 11;

// Mayfly pins connected to control respective solenoids relays.
int solenoid_pins[] = { 23, 7, 9, 10 };

// Pump
int dir1PinA = 8;
int dir2PinA = 6;
int speedPinA = 4;  // Needs to be a PWM pin to be able to control motor speed

// Heating Element
int dir1PinB = 18;
int dir2PinB = 20;
int speedPinB = 5;  // Needs to be a PWM pin to be able to control motor speed

//Methane Calculations
float Rs;
float Ro = 23250;  // ohms
float Rl = 3170;
float Vdd = 5;
float Vload;
float ratio_corr;
float CH4_raw;
float CH4_log;
float CH4_ratio;
float waterLevel;

String heater = "off";



void setup() {

  Wire.begin();

  // Set OUTPUT Pins on Mayfly Microcontroller
  pinMode(dir1PinA, OUTPUT);
  pinMode(dir2PinA, OUTPUT);
  pinMode(dir1PinB, OUTPUT);
  pinMode(dir2PinB, OUTPUT);
  pinMode(speedPinA, OUTPUT);
  pinMode(flushPin, OUTPUT);
  pinMode(solenoid_pins[0], OUTPUT);
  pinMode(solenoid_pins[1], OUTPUT);
  pinMode(solenoid_pins[2], OUTPUT);
  pinMode(solenoid_pins[3], OUTPUT);

  //HIGH implies off for relay board
  digitalWrite(flushPin, HIGH);
  digitalWrite(solenoid_pins[0], HIGH);
  digitalWrite(solenoid_pins[1], HIGH);
  digitalWrite(solenoid_pins[2], HIGH);
  digitalWrite(solenoid_pins[3], HIGH);

  //Begins serial communication with 9600 Baud
  Serial.begin(9600);

  //Set the gain for each ADC located on AA0,AA1, AA2, and AA3 on Mayfly Microcontroller
  ads1.setGain(GAIN_ONE);  // 1x gain   +/- 4.096V  1 bit = 2mV      0.125mV
  //Set the gain for ADS1115 ADC
  ads2.setGain(GAIN_ONE);  // 1x gain   +/- 4.096V  1 bit = 2mV      0.125mV

  //Check if ADC on mayfly is operational at 0x48 address
  if (!ads1.begin(0x48)) {
    Serial.println("Failed to initialize ADS1.");
    while (1)
      ;
  }


  //Check if ADS1115 ADC is operational at 0x49 address
  if (!ads2.begin(0x49)) {
    Serial.println("Failed to initialize ADS2.");
    while (1)
      ;
  }

  //Sets BME1 I2C Location to 0x76
  if (!bme1.begin(0x76)) {
    Serial.println("Could not find a valid BME280 sensor, check wiring!");
    while (1)
      ;
  }
  //Sets BME2 I2C Location to 0x77
  if (!bme2.begin(0x77)) {
    Serial.println("Could not find a valid BME280 sensor, check wiring!");
    while (1)
      ;
  }

  //Initialise log file
  setupLogFile();

}

void loop() {

  //Force Reset of for loop because unknown reason k++ increased infinitely
  k = 0;
  //___________Valve Control____________________________//
  
//for loop opens a specified solenoid, extracts gas, takes measurements, and loops to next solenoid

  for (k = 0; k < 4; k++) {
    int active_solpin = solenoid_pins[k];

    //add a list of solenoid pin numbers and go through them to activate solenoid!

    //Careful now! If pin eight is used for a solenoid it triggers the relay sporadically if mayfly is restarted

    //Turn specified solenoid on for delay(seconds)
    digitalWrite(active_solpin, LOW);
    delay(1000);

    //Turn the Pump ON for delay(seconds) 6000 is enough to fill the entire chamber at max pump speed
    analogWrite(speedPinA, 255);  //Sets speed variable via PWM
    digitalWrite(dir1PinA, LOW);
    digitalWrite(dir2PinA, HIGH);
    delay(6000);

    //Turn the Pump OFF to let gas diffuse in chamber for delay(seconds)
    analogWrite(speedPinA, 0);  //Sets speed variable via PWM
    digitalWrite(active_solpin, HIGH);
    delay(10000);

    // Read Oxygen and CO2 results from the Mayfly ADCs
    results1 = ads1.readADC_Differential_0_1();
    results2 = ads1.readADC_Differential_2_3();
    // Read battery level and methane voltage from ADS1115
    results3 = ads2.readADC_SingleEnded(0);
    results4 = ads2.readADC_SingleEnded(1);

    //Read results from both BME280s. a specifies ambient
    atemp = bme1.readTemperature();
    apressure = bme1.readPressure() / 100.0F;
    ahumidity = bme1.readHumidity();
    temp = bme2.readTemperature();
    pressure = bme2.readPressure() / 100.0F;
    humidity = bme2.readHumidity();


    //Compute voltage from ADC results
    O2_Volt = results1 * multiplier / 1000;
    CO2_Volt = results2 * multiplier / 1000;
    Battery_Lvl = results3 * multiplier / 1000;
    Methane_Volt = results4 * multiplier / 1000;

    //_______________Algorithm Computation_______________________________________

    //Converts Voltage to Percent O2%
    O2_Percentage = (((0.0763 * abs(O2_Volt)) - 0.0841) * 100);

    //Error Reading if negative value
    if (O2_Percentage <= 0) {
      O2_Percentage = -999;
    }

    //Converts Volts CO2 to PPM
    //CO2_PPM = (1671.4 * abs(CO2_Volt) - 1287.3);
    //CO2_PPM = (1671.4 * abs(CO2_Volt) - 1287.3);
    //CO2_PPM = (-178.56 * pow(abs(CO2_Volt),2)) + (2608.7 * abs(CO2_Volt)) - 2297.3;
    // CO2_PPM = 3746.1 * log(abs(CO2_Volt)) - 52.951;
    CO2_PPM = (687.33 * pow(abs(CO2_Volt),3)) - (4334.2 * pow(abs(CO2_Volt),2)) + (9383.9 * abs(CO2_Volt)) - 5605.8;

    //Error Reading if negative value
    if (CO2_PPM <= 0) {
      CO2_PPM = -999;
    }

    //Converts Volts CH4 to PPM
    Methane_PPM = 8.2318 * pow(2.71828, (2.7182 * Methane_Volt));

    //Error Reading if negative value
    if (Methane_PPM <= 0) {
      Methane_PPM = -999;
    }


    //Heating element connected to L298N H-Bridge. Heat the sensor chamber if temperature is nearing ambient
    if (temp < atemp + 2) {
      //Heating Element ON
      analogWrite(speedPinB, 50);  //Sets voltage supplied to heating element from 0-255
      digitalWrite(dir1PinB, LOW);
      digitalWrite(dir2PinB, HIGH);
      heater = "ON";
    } else {
      //Heating Element OFF
      analogWrite(speedPinB, 0);  //Sets voltage supplied to zero
      digitalWrite(dir1PinB, LOW);
      digitalWrite(dir2PinB, HIGH);
      heater = "OFF";
    }

    //Compute the battery voltage based on ADS1115 readings of voltage divider
    float R_load = 9862.939;
    float R_1 = 99725.277;
    Battery_Lvl = ((Battery_Lvl * (R_load+ R_1)) / R_load);
    //Currently no conditions are set to power off the device if battery voltage is to low

    //Measure voltage from Capacitive Soil Moisture Sensor
    waterLevel = analogRead(A0);

    // Creates data string from function
    String dataRec = createDataRecord();

    //Display Measurements to Serial Monitor
    Serial.println("-----------------------------------------------------------------------------");

    //Informs Solenoid used
    Serial.print("Solenoid");
    solenoid = (k + 1);
    Serial.print(solenoid);
    Serial.print("| ");

    //Informs if heater element is active
    Serial.print("Heater ");
    Serial.print(heater);
    Serial.print("| ");

    // Serial.print("Methane = ");
    // Serial.print(Methane_PPM);
    // Serial.print("PPM, ");

    Serial.print("Water = ");
    Serial.print(waterLevel);
    Serial.print(" Moisture| ");

    Serial.print("CO2 = ");
    Serial.print(CO2_Volt,3);
    Serial.print("V, ");

    Serial.print("CO2 = ");
    Serial.print(CO2_PPM);
    Serial.print("PPM, ");

    Serial.print("O2 Volt= ");
    Serial.print(O2_Volt);
    Serial.print("V| ");

    Serial.print("O2% = ");
    Serial.print(O2_Percentage);
    Serial.print("%| ");

    Serial.print("CH4 Volt = ");
    Serial.print(Methane_Volt);
    Serial.print("V| ");

    Serial.print("CH4 PPM = ");
    Serial.print(CH4_log);
    Serial.print("PPM| ");

    Serial.print("Temperature = ");
    Serial.print(temp);
    Serial.print("C| ");

    Serial.print("RH = ");
    Serial.print(humidity);
    Serial.print("%| ");


    Serial.print("\n");

    Serial.print("Ambient Temperature = ");
    Serial.print(atemp);
    Serial.print("C| ");

    Serial.print(" Ambient RH = ");
    Serial.print(ahumidity);
    Serial.print("%| ");

    Serial.print("\n");
    Serial.println("-----------------------------------------------------------------------------");
    //End Barrier for serial monitor


    //Save the data record to the log file
    logData(dataRec);

    delay(1000);
  }
}

String createDataRecord() {
  //Requests data from RTC
  year = Clock.getYear();
  hour = Clock.getHour(h24, PM);
  minute = Clock.getMinute();
  second = Clock.getSecond();
  month = Clock.getMonth(Century);
  DayMonth = Clock.getDate();

  //Create a String type data record in csv format seperated by commas
  String data = "";
  data += month;
  data += "/";
  data += DayMonth;
  data += "/";
  data += "20";
  data += year;
  data += ",";
  data += hour;
  data += ":";
  data += minute;
  data += ",";
  data += solenoid;
  data += ",";
  data += heater;
  data += ",";
  data += waterLevel;
  data += ",";
  data += O2_Percentage;
  data += ",";
  data += O2_Volt;
  data += ",";
  data += CO2_PPM;
  data += ",";
  data += CO2_Volt;
  data += ",";
  data += CH4_log;
  data += ",";
  data += Methane_Volt;
  data += ",";
  data += atemp;
  data += ",";
  data += ahumidity;
  data += ",";
  data += apressure;
  data += ",";
  data += temp;
  data += ",";
  data += humidity;
  data += ",";
  data += pressure;
  return data;
}

//Initialise the SD card and creates file if not there
void setupLogFile() {
  //Checks if SD Card is missing
  if (!SD.begin(SD_SS_PIN)) {
    Serial.println("Error: SD card failed to initialise or is missing.");
  }

  //Check if the file already exists
  bool oldFile = SD.exists(FILE_NAME);

  //Open the file in write mode
  File logFile = SD.open(FILE_NAME, FILE_WRITE);

  //Add header information if the file did not already exist
  if (!oldFile) {
    logFile.println(LOGGERNAME);
    logFile.println(DATA_HEADER);
  }

  //Close the file to save it
  logFile.close();
}

//Creates function to save data in a string
void logData(String rec) {
  //Re-open the file
  File logFile = SD.open(FILE_NAME, FILE_WRITE);

  //Write the CSV data
  logFile.println(rec);

  //Close the file to save it
  logFile.close();
}

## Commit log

2022-11-02 Create STL Files
2023-03-31 Pump Speed Control
    Implemented an H-Bridge to control Pump speed using Pulse Width Modulation (PWM).
2023-04-10 All components connected
    All components have been connected on a prototype solder board. This includes CO2, Methane, O2 monitoring along with solenoid and pump operation.
2023-04-19 Update Soil_Program.ino
    Installed a water pump, installed heater element
2023-04-19 Update Soil_Program.ino
    Add heater element regulation based on difference in temperature and ambient temperature
2023-05-05 Add files via upload
    Electrical Schematic of the device
